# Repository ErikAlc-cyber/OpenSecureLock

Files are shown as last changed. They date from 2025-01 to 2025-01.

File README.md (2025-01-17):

# Open Secure Lock

### Descripción
Este proyecto presenta un **sistema de acceso inteligente** diseñado para mejorar la seguridad en unidades habitacionales y edificios departamentales. El prototipo combina tecnologías modernas, como **NFC**, **contraseñas numéricas**, y **detección de intrusiones**, para ofrecer una solución accesible, eficiente y confiable para proteger hogares frente a posibles robos o accesos no autorizados.

### Características Principales
- **Doble Autenticación:** Combinación de tarjetas NFC y contraseñas numéricas para maximizar la seguridad.
- **Detección de Intrusión:** Sensores infrarrojos y de presión que alertan sobre accesos no autorizados.
- **Notificaciones en Tiempo Real:** Alertas enviadas vía WhatsApp a usuarios y administradores en caso de intentos de acceso no autorizados.
- **Respaldo Energético:** Sistema alimentado por baterías recargables y puerto de carga externa para asegurar el funcionamiento incluso en cortes de energía.
- **Plataforma Web:** Gestión de usuarios y visualización de bitácoras de accesos mediante una interfaz web intuitiva.
- **Diseño Modular:** Facilita la instalación y el mantenimiento del sistema.

### Instalación
1. **Requisitos de Hardware:**
   - Microcontrolador Raspberry Pi Pico W.
   - Módulo NFC MFRC-522.
   - Pantalla LCD1602 I2C.
   - Sensores infrarrojos y de presión.
   - Otros componentes listados en la sección Inventario de Activos.

2. **Requisitos de Software:**
   - **Thonny IDE:** Para cargar y depurar el código en MicroPython.
   - **CallMeBot API:** Para enviar notificaciones vía WhatsApp.
   - **Biblioteca de LCD para pico:** para controlar la LCD. Encuéntrala [aquí!](https://github.com/T-622/RPI-PICO-I2C-LCD)

3. **Pasos para Configurar el Prototipo:**
   - [ ] Instalar y configurar los módulos de hardware según el Diagrama de Conexión.
   - [ ] Cargar el firmware en el microcontrolador utilizando el entorno de desarrollo.
   - [ ] Configurar las credenciales de usuario y administrador en la plataforma web.
   - [ ] Realizar pruebas iniciales para verificar el funcionamiento de los módulos.

### Cómo Funciona
1. **Acceso Seguro:**
   - El usuario escanea su tarjeta NFC y proporciona su contraseña numérica en el teclado.
   - Si la autenticación es exitosa, se desbloquea la cerradura electrónica.
2. **Alerta por Intrusión:**
   - Sensores detectan movimientos sospechosos o aperturas no autorizadas de la puerta.
   - Se envía una notificación a través de WhatsApp al usuario y administrador.
3. **Monitoreo y Gestión:**
   - La plataforma web permite realizar altas, bajas y cambios de usuarios, además de consultar bitácoras.

### Diseño de la Base de Datos

El sistema utiliza una base de datos estructurada que permite gestionar eficientemente la información de usuarios, accesos y registros de actividad. A continuación, se presenta el diseño de la base de datos:

#### Descripción
- **Usuarios:** Almacena información básica de los usuarios, como ID, nombre, tarjeta NFC asociada y contraseña encriptada.
- **Registros de Acceso:** Lleva un historial de accesos exitosos y fallidos, incluyendo la fecha y hora del intento.
- **Administradores:** Contiene las credenciales y permisos del administrador del sistema.
- **Configuraciones:** Guarda datos del sistema.

#### Diagrama de la Base de Datos
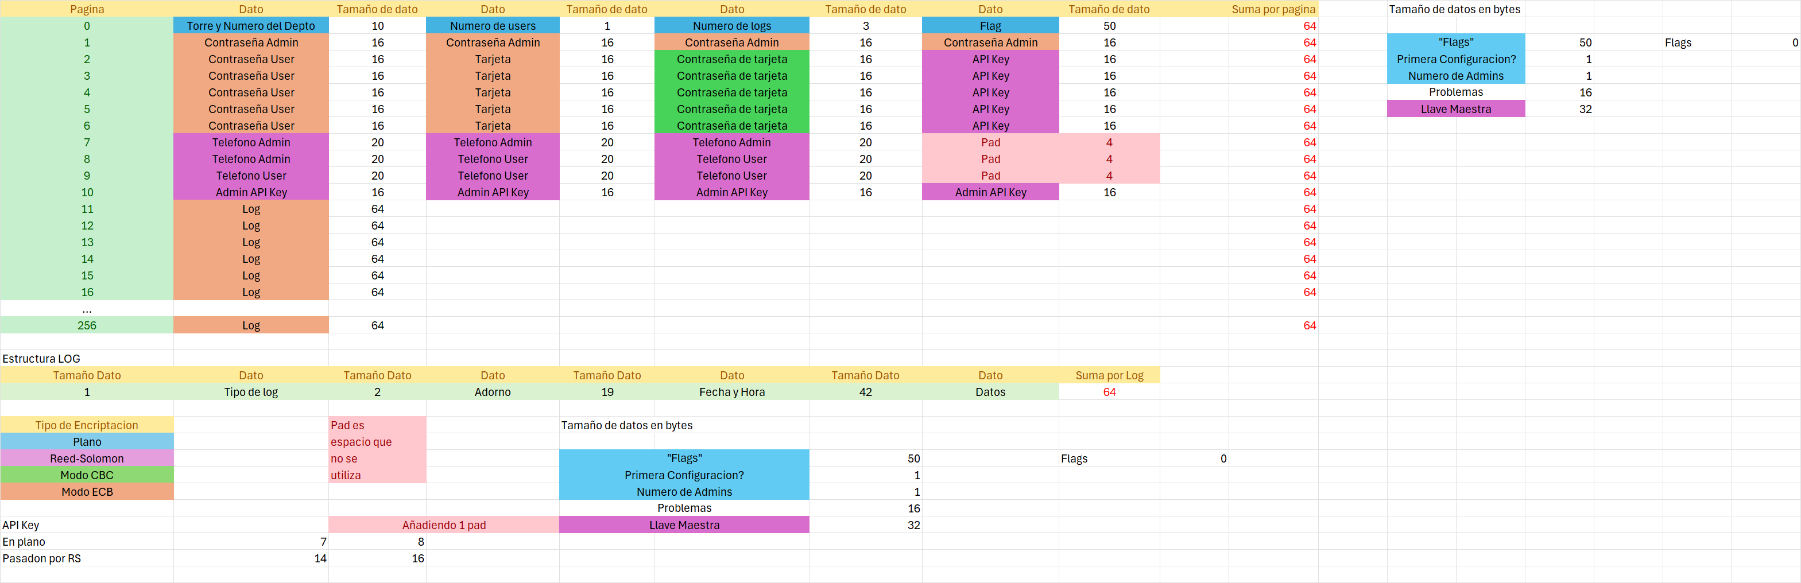
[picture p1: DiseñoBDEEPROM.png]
Diagrama de Base de Datos


#### Diagrama electrico
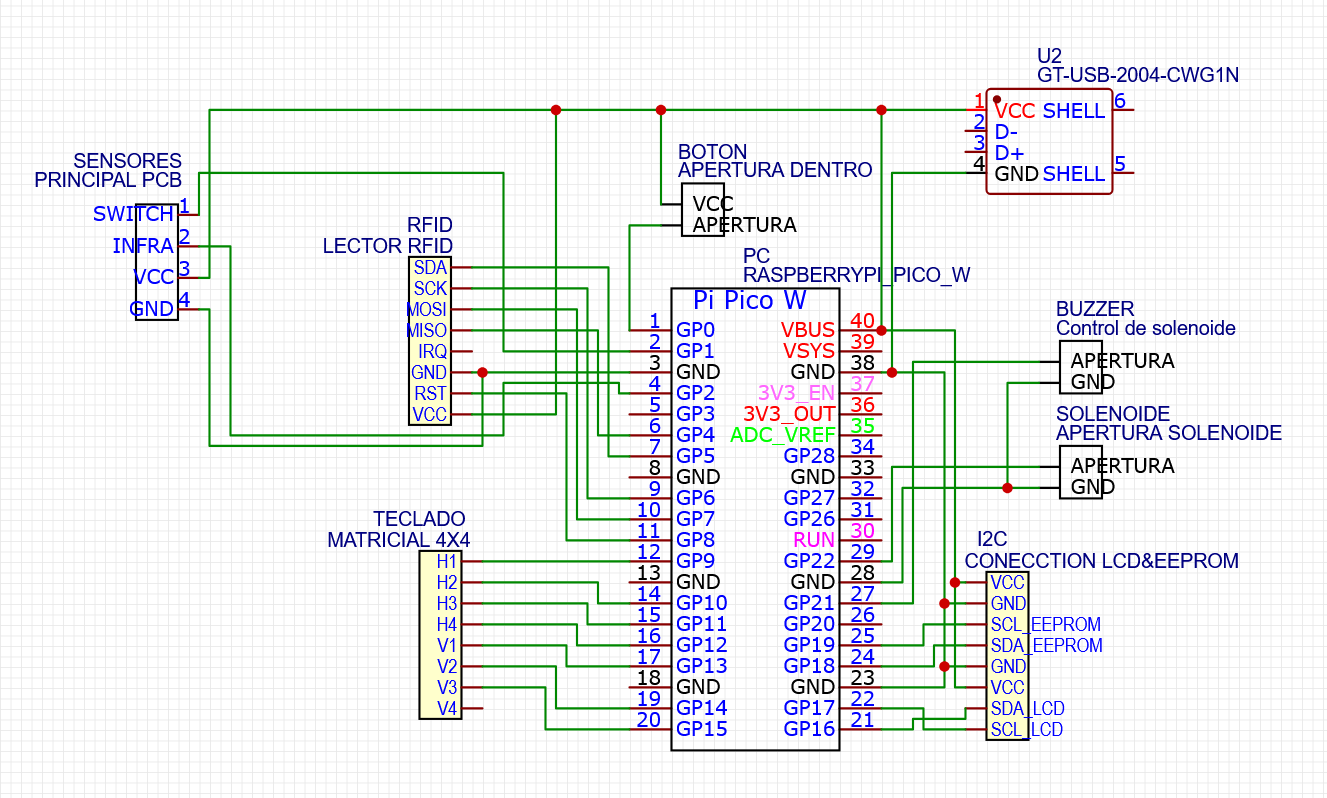
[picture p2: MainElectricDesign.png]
Diagrama de electrico principal

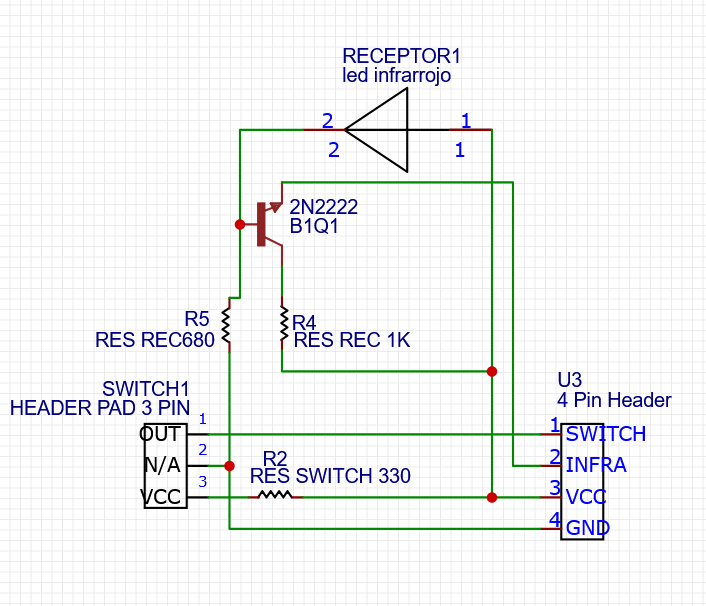
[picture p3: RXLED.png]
Diagrama de electrico de LED Receptor

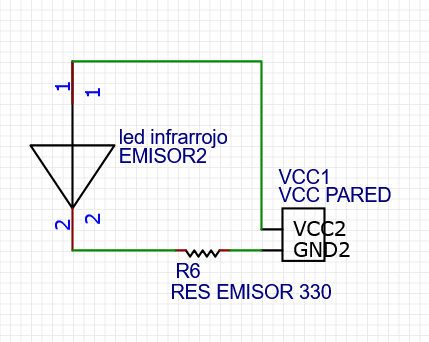
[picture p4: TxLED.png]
Diagrama de electrico de LED Transmisor


#### Prototipo Final
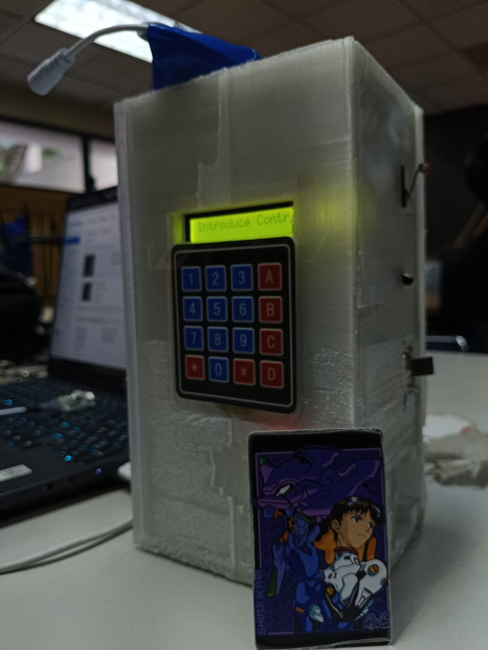
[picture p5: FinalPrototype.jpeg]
Prototipo Final


### Uso Futuro
El prototipo se puede expandir con:
- Integración de asistentes virtuales como Alexa o Google Assistant.
- Uso de teléfonos móviles con NFC como llaves de acceso.
- Adición de cámaras de vigilancia conectadas al sistema.

### Créditos
Desarrollado por:
- **Erik Alcántara Covarrubias** (ealcantarac1700@alumno.ipn.mx)
- **Benjamín Ortiz Rangel** (bortizr1600@alumno.ipn.mx)
- **Ana Paola Santos Mendoza** (asantosm1700@alumno.ipn.mx)

---

¡Contribuciones y retroalimentación son bienvenidas!

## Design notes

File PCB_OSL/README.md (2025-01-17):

# Diseño de la PCB para la cerradura

Este es el diseño completo de OSL, la PCB esta hecha para que se pueda mandar a pedir en una sola pieza y después romperla en los componentes necesarios

## Mejoras
Estamos concientes de que se puede mejorar la PCB, el diseño no es el final pero debe servir de base para después mejorarlo poco a poco

## Cómo usarlo

1. En el editor, abre el documento desde:  
   **Menú superior** → **Archivo** → **Abrir** → **EasyEDA**...  
2. Selecciona el archivo JSON correspondiente y ábrelo en el editor.  
3. Puedes guardar el diseño como un proyecto.

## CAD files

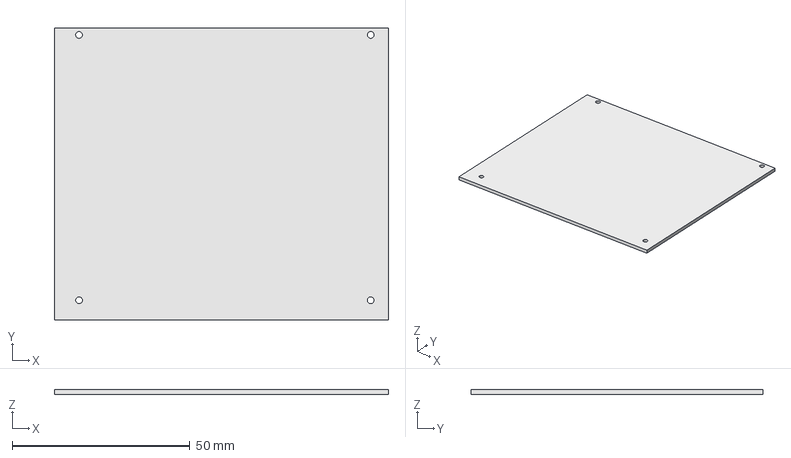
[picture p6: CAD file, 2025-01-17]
Case-3D-File/case.FCStd
93.9 x 82.0 x 1.40 mm

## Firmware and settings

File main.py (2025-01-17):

import mfrc522
from CAT24C256 import EEPROMManager
import keypad4x4
from ucryptolib import aes
import random
import time
import utime
from machine import Pin, PWM, I2C
from DatabaseManager import DatabaseManager as db
import rtc_config
from lcd_api import LcdApi
from pico_i2c_lcd import I2cLcd
from webserver import WiFiManager, WebServer
import uasyncio as asyncio
import sys
import network
import requests

MODE_CBC = 2
BLOCK_SIZE = 16
LCD_NUM_ROWS = 2
LCD_NUM_COLS = 16
LCD_ADDR = 0x27

# Configuracion de Hardware
BUZZER = PWM(Pin(21, mode=Pin.OUT))
BUZZER.freq(500)
OPEN_BTN = Pin(0, mode=Pin.IN, pull=Pin.PULL_DOWN)
DOOR_SENSOR = Pin(1, mode=Pin.IN, pull=Pin.PULL_DOWN)
IR_SENSOR = Pin(2, mode=Pin.IN, pull=Pin.PULL_DOWN)
DOOR_OUT = Pin(22, mode=Pin.OUT)

# Configuracion de la EEPROM
eeprom= EEPROMManager(0x50, 256, 1, 19, 18)
database = db()
database.read_general_info()

#Configuración LCD
i2c = I2C(0, sda=Pin(16), scl=Pin(17), freq=400000)
lcd = I2cLcd(i2c, LCD_ADDR, LCD_NUM_ROWS, LCD_NUM_COLS)
   
# Clase para inicializar la configuración
class setup_wizard:
    def __init__(self,newcode = False) -> None:
        self.newcode = newcode
        self.routes = [
            {
                '/': '/TT_pagina/Setupprincipal.html',
                '/edif': '/TT_pagina/Edificio.html',
                '/admin':'/TT_pagina/adminsetup.html',
                '/alta':'/TT_pagina/altasetup.html',
                '/config': '/TT_pagina/conectarsetup.html',
                '/styles':'/TT_pagina/styles.css',
            },
            {
                '/': '/TT_pagina/index.html',
                '/config': '/TT_pagina/conectarWifi.html',
                '/alta':'/TT_pagina/altaUsuario.html',
                '/baja':'/TT_pagina/bajaUsuario.html',
                '/cambio':'/TT_pagina/cambioUsuario.html',
                '/log':'/TT_pagina/logs.html',
                '/admin':'/TT_pagina/admin.html',
                '/styles':'/TT_pagina/styles.css',
            }]
        self.wifi_manager = WiFiManager(ssid="TT_2024-B037", password="12345678")
        prim_config = 1 if database.flags[0] == 49 else 0
        self.web_server = WebServer(self.wifi_manager, self.routes, prim_config)
    
    def no_config(self) -> None:
        """Genera una nueva contraseña aleatoria."""
        random_pwsd = [random.randint(0, 255) for _ in range(6)]
        self.newcode = True
        self.wifi_manager.start_ap()
        
    async def start(self):
        print("Iniciando servidor web en modo administración...")
        await self.web_server.start_server()

async def admin_mode(wizard):
    """Modo administración que inicia el servidor web."""
    wizard.no_config()
    await wizard.start()

# Clase para manejar tarjetas RFID
class RFIDCard:
    def __init__(self) -> None:
        self.uid = 0 # Identificador único de la tarjeta
        self.flag = False  # Indica si la tarjeta es válida
    
    def ReadData(self, block=8):
        """
        Lee los datos de la tarjeta RFID.
        
        :param block: Bloque de datos a leer (default: 8).
        :return: True si se leyó con éxito, False en caso contrario.
        """
        rdr = mfrc522.MFRC522(sck=6, miso=4, mosi=7, cs=5, rst=8)
        (stat, tag_type) = rdr.request(rdr.REQIDL)
        if stat == rdr.OK:
            (stat, raw_uid) = rdr.anticoll()
            if stat == rdr.OK:
                self.uid = "%02x%02x%02x%02x" % (raw_uid[0], raw_uid[1], raw_uid[2], raw_uid[3])
                if rdr.select_tag(raw_uid) == rdr.OK:
                    key = [0xFF, 0xFF, 0xFF, 0xFF, 0xFF, 0xFF]  # Clave de autenticación
                    if rdr.auth(rdr.AUTHENT1A, block, key, raw_uid) == rdr.OK:
                        data = rdr.read(block)
                        self.flag = True
                        return self.flag
                    else:
                        print("AUTH ERR")
                else:
                    print("Failed to select tag")
        
        database.save_log("Tarjeta: No se pudo leer la tarjeta",3)
        
            
    def WriteData(self, databytes, block=8):
        """
        Escribe datos en la tarjeta RFID.
        
        :param databytes: Datos a escribir.
        :param block: Bloque donde se escribirán los datos (default: 8).
        :return: True si se escribió con éxito, False en caso contrario.
        """
        rdr = mfrc522.MFRC522(sck=6, miso=4, mosi=7, cs=5, rst=8)
        (stat, tag_type) = rdr.request(rdr.REQIDL)
        if stat == rdr.OK:
            (stat, raw_uid) = rdr.anticoll()
            if stat == rdr.OK:
                if rdr.select_tag(raw_uid) == rdr.OK:
                    key = [0xFF, 0xFF, 0xFF, 0xFF, 0xFF, 0xFF] # Clave de autenticación
                    if rdr.auth(rdr.AUTHENT1A, block, key, raw_uid) == rdr.OK:
                        stat = rdr.write(block, databytes)
                        rdr.stop_crypto1()
                        if stat == rdr.OK:
                            self.flag = False
                            database.save_log("Tarjeta: Se creo nueva contraseña de acceso",2)
                            return self.flag
                        else:
                            database.save_log("Tarjeta: No se pudo escribir",3)
                            print("FAILED")
                    else:
                        print("AUTH ERR")
                        database.save_log("Tarjeta: Error de autenticacion",3)
                else:
                    print("Failed to select tag")
                    database.save_log("Tarjeta: No se pudo leer la tarjeta",3)
        else:
            print("stat Failure")
            database.save_log("Tarjeta: error en stat",3)
        
        return self.flag
    
    def ban_uid(self):
        """Reinicia el UID y la bandera de estado."""
        self.uid = ""
        self.flag = False 

# Clase para manejar los sensores de la puerta
class Door_sensors:
    def __init__(self)->None:
        self.ir_flag = True
        self.door_flag = True
        
    def irq_ir(self, Pin):
        """
        Interrupción para el sensor infrarrojo.
        """
        if(self.ir_flag):
            print("IR Sensor Triggered")
            database.save_log("Sensor: Sensor infrarojo activado",2)
            #send_message(phone_number, api_key, "Se detecto un intento de entrada sospechoso en su domicilio")
        utime.sleep(0.3)
    
    def irq_door(self, Pin):
        """Interrupción para el sensor de la puerta."""
        print("Door Sensor Triggered")
        if(self.door_flag):
            print("Empezar a sonar buzzer")
            BUZZER.duty_u16(10000)
            database.save_log("Sensor: Sensor de puerta activado",2)
            #send_message(phone_number, api_key, "Se detecto un intento de entrada sospechoso en su domicilio")
        utime.sleep(0.3)
    
    def irq_open(self, Pin):
        """Interrupcion para abrir la puerta con el boton proporcionado"""
        print("Interrupcion de apertura de puerta")
        self.defuse_door()
        self.defuse_ir()
        print("Sensores desactivados")
        DOOR_OUT.toggle()
        print("Solenoide Activado")
        DOOR_OUT.toggle()
        print("Solenoide desactivado")
        
                
    def defuse_door(self):
        """Desactiva la alarma de la puerta."""
        self.door_flag = False 
    
    def defuse_ir(self):
        """Desactiva la alarma del sensor infrarrojo."""
        self.ir_flag = False
        
    def change_state(self):
        while DOOR_SENSOR.value() == 1:
            utime.sleep(0.05)
            self.defuse_ir()
            self.defuse_door()
            
        while DOOR_SENSOR.value() == 0:
            utime.sleep(0.05)
            
        self.activate_def()
        
    def activate_def(self):
        """Activa ambas alarmas."""
        self.door_flag = True
        self.ir_flag = True 

def url_encode(input_string):
    """
    Codifica una string en formato URL.
    :param input_string: La string a codificar.
    :return: La string codificada en formato URL.
    """
    # Mapa de caracteres permitidos en URL
    allowed_chars = (
        "ABCDEFGHIJKLMNOPQRSTUVWXYZ"
        "abcdefghijklmnopqrstuvwxyz"
        "0123456789"
        "-_.~"
    )
    
    encoded_string = ""
    for char in input_string:
        if char in allowed_chars:
            encoded_string += char
        else:
            encoded_string += f"%{ord(char):02X}"  # Convierte a hexadecimal
    
    return encoded_string

def send_message(phone_number, api_key, message, debug=0):
    """
    Envia un mensaje por WhatsApp.

    :param phone_number: Número al que se enviará el mensaje.
    :param api_key: Clave de la API para ese número.
    :param message: Mensaje que se enviará.
    :param debug: Saber si se requiere el modo depurado.
    :return: Valor booleano.
    """
    url = f'https://api.callmebot.com/whatsapp.php?phone=+521{phone_number}&text={message}&apikey={api_key}'
    try:
        response = requests.get(url)
        if response.status_code == 200:
            if debug == 1:
                print(f"Mensaje enviado a {phone_number}: {message}")
            database.save_log(f"Mensaje enviado", 2)
            return True
        else:
            if debug == 1:
                print(f"Fallo al enviar mensaje a {phone_number}: {response.text}")
            return False
    except Exception as e:
        error = f"Error enviando mensaje: {str(e)}"
        if debug == 1:
            print(error)
        database.save_log(error, 3)
        return False
        
def send_bulk_messages(message, admin_only=False, debug=0):
    """
    Envia mensajes a todos los números telefónicos recuperados.

    :param message: Mensaje que se enviará.
    :param admin_only: Indica si solo se debe enviar a números de administradores.
    :param debug: Saber si se requiere el modo depurado.
    """
    try:
        # Recuperar teléfonos y API keys
        print("*****Empezando mensajeria masiva*****")
        message = url_encode(message)
        phone_numbers = database.read_phones()
        #TODO Solucionar API
        admin=1 if admin_only else 0
        api_keys = database.get_api(admin)

        # Validar que haya datos suficientes
        if len(phone_numbers) != len(api_keys):
            raise ValueError("El número de teléfonos no coincide con el de claves API.")
        
        for phone, api in zip(phone_numbers, api_keys):
            if len(api) == 7:  # Verificar que la clave API tenga la longitud correcta
                send_message(phone, api, message, 1)
            else:
                error = f"Clave API inválida para {phone}: {api}"
                if debug:
                    print(error)
                database.save_log(error, 3)

    except Exception as e:
        error = f"Error al enviar mensajes masivos: {str(e)}"
        print(error)
        if debug:
            print(error)
        database.save_log(error, 3)
   
def lcd_str(text, row=0, col=0, delay=0.3):
    """
    Muestra texto en el LCD, desplazándolo si excede el límite de caracteres por fila.
    text: String que se desea mostrar.
    row: Fila donde se inicia la impresión del texto.
    col: Columna inicial para comenzar la impresión.
    delay: Tiempo de retraso entre cada desplazamiento si el texto es largo.
    """
    lcd.clear()  # Limpia la pantalla antes de mostrar el nuevo texto
    text += " "

    # Calcula el límite de caracteres por fila
    max_chars = LCD_NUM_COLS - col

    # Si el texto cabe en la pantalla, simplemente mostrarlo
    if len(text) <= max_chars + 1:
        lcd.move_to(col, row)
        lcd.putstr(text)
    else:
        # Si el texto excede el límite, mostrarlo en partes
        start = 0
        end = max_chars
        while True:
            # Calcula la ventana del texto para mostrar en pantalla
            end = start + max_chars
            lcd.move_to(col, row)
            if end <= len(text):
                lcd.putstr(text[start:end])
            else:
                # Si el final excede el largo del texto, envuelve al inicio
                lcd.putstr(text[start:] + text[:end - len(text)])

            time.sleep(1)  # Espera antes de desplazar

            # Avanza en el texto y envuelve si llega al final
            start = (start + 1) % len(text)

def random_shuffle(cadena, semilla=None):
    """
    Mezcla aleatoriamente los caracteres de una cadena.
    
    :param cadena: Cadena a mezclar.
    :param semilla: Semilla para la aleatoriedad.
    :return: Cadena mezclada.
    """
    if semilla is not None:
        urandom.seed(semilla)
    
    caracteres = list(cadena)
    longitud = len(caracteres)
    
    for i in range(longitud):
        indice_aleatorio = random.randint(0, longitud - 1)
        caracteres[i], caracteres[indice_aleatorio] = caracteres[indice_aleatorio], caracteres[i]
    
    cadena_mezclada = ''.join(caracteres)
    return cadena_mezclada

def bytes_random(length):
    """
    Genera bytes aleatorios.
    
    :param length: Longitud de los bytes aleatorios.
    :return: Bytes aleatorios.
    """
    random_bytes = bytes([random.randint(0, 255) for _ in range(length)])
    return random_bytes

def create_key(raw_uid):
    """
    Crea una clave AES a partir del UID de la tarjeta RFID.
    
    :param raw_uid: UID de la tarjeta.
    :return: Clave cifrada.
    """
    aes_key = bytes_random(16)
    iv = bytes_random(16)
    cipher = aes(aes_key, 2, iv)
    plaintext = random_shuffle(raw_uid)
    pad = 16 - len(plaintext) % 16
    plaintext = plaintext + " "*pad
    encrypted = iv + cipher.encrypt(plaintext)
    return encrypted

def pad_data(data: str, length: int) -> str:
    if len(data) >= length:
        return data
    padded_data = data + ' ' * (length - len(data))
    return padded_data

def main_loop(intentos):
    """Ciclo principal del programa."""
    utime.sleep(1)
    BUZZER.duty_u16(0) # Apaga el zumbador
    admin_flag = False
    stage_1 = True
    stage_2 = False
    while True:
        #inicio = time.ticks_ms()        
            
        # Manejo de intentos
        if intentos >= 3:
            database.save_log("Se detecto intento de entrada sospechoso",2)
            #TODO Agregar mensaje whats
            send_bulk_messages(f"{database.depto_info}: Se detecto intento de entrada sospechoso", 1)
            #send_message(phone_number, api_key, "Se detecto intento de entrada sospechoso en su domicilio")
            intentos = 0
            stage_1 = True
            stage_2 = False
                
        if stage_1:
                
            #Introducir codigo en le keypad
            print("")
            print("Introduce Contra")
            print("")
            lcd_str("Introduce Contra", 0,0)
    
            psk_code = ""
            intentos += 1
            # Ciclo para hacer display de la contraseña
            while True:
                key = keypad.Keypad4x4Read()
                if key is not None:
                    print(f"Tecla presionada: {key} type: {type(key)}")
                    
                    if key == "#":  # Fin de la entrada
                        break
                    elif key == "*":
                        psk_code = psk_code[:len(psk_code) - 1]
                    else:
                        psk_code += key  # Agrega la tecla a la cadena
                    
                    display = "*" * len(psk_code)
                    lcd_str(display, 0,0)
                utime.sleep(0.3)  # Espera un tiempo para evitar múltiples lecturas
            
            pwd = pad_data(psk_code, 16)
            print(f"Texto pad: {pwd} type: {type(pwd)}")
            
            #TODO Modificar a leer de la eeprom
            if database.is_admin(pwd):
                sensores.defuse_ir()
                sensores.defuse_door()
                intentos = 0
                admin_flag = True
                lcd_str("Admin",0,0)
                print("****Se salio de Admin****")
                prim_config = False if database.flags[0] == 49 else True
                if prim_config:
                    lcd_str("Modo admin", 0,0)
                    asyncio.run(admin_mode(wizard))
                    admin_flag = False
                    del pwd
                    break
                database.save_log("Se ingreso contraseña administrador",1)
                
            if database.is_user(pwd):
                intentos = 0
                database.save_log("Se ingreso contraseña",1)
                if admin_flag:
                    psk_code = ""
                    lcd_str("1 Web / 2 Abrir", 0,0)
                    
                    while True:
                        key = keypad.Keypad4x4Read()
                        if key is not None:
                            
                            if key == "1":  # Fin de la entrada
                                lcd_str("Modo admin", 0,0)
                                database.save_log("Se activo modo admin",1)
                                asyncio.run(admin_mode(wizard))
                                admin_flag = False
                                del pwd
                                break
                            
                            elif key == "2":
                                lcd_str("Autorizado", 0,0)
                                mensaje = "Acceso concedido con codigo"
                                database.save_log(mensaje,1)
                                #TODO Agregar mensaje whats
                                #send_bulk_messages("Acceso concedido", True, 1)
                                DOOR_OUT.toggle()
                                stage_1 = True
                                stage_2 = False
                                intentos = 0
                                #TODO Agregar funcion cambio de estado
                                #sensores.change_state()
                                time.sleep(2)
                                DOOR_OUT.toggle()
                                del pwd
                                break
                            else:
                                lcd_str("Incorrecto", 0,0)
                                utime.sleep(2)
                            
                    
                        utime.sleep(0.3)  # Espera un tiempo para evitar múltiples lecturas
                else:
                    stage_1 = False
                    stage_2 = True
            
            else:
                psk_code = None
            pass
                    
        if stage_2:
            print("")
            print("Acerca Tarjeta")
            print("")
            lcd_str("Acerca Tarjeta", 0,0)
            
            if CardObject.ReadData(12):
                #TODO Cambiar a leer de la eeprom
                print(f"Tarjeta actual: {pad_data(CardObject.uid, 16)} Tarjeta de usuario: {database.usr_card}")
                if (pad_data(CardObject.uid, 16) == database.usr_card):
                    print("Tarjeta Autorizada")
                    if CardObject.flag:
                        print(f"Tarjeta flag: {CardObject.flag}")
                        new_key=create_key(CardObject.uid)
                        print(f"Llave nueva: {new_key}")
                        if CardObject.WriteData(new_key, 12):
                            lcd_str("Error", 0,0)
                            mensaje = "Error en tarjeta"
                            database.save_log(mensaje,3)
                        else:
                            lcd_str("Autorizado", 0,0)
                            page = database.usr_start_page + database.usr_id_num
                            #TODO Agregar update a medias
                            eeprom.partial_data(page, 48, new_key[:16])
                            mensaje = "Acceso concedido a tarjeta"
                            database.save_log(mensaje,1)
                            #TODO Agregar mensaje whats
                            #send_bulk_messages("Acceso concedido")
                            DOOR_OUT.toggle()
                            stage_1 = True
                            stage_2 = False
                            intentos = 0
                            #TODO Agregar funcion cambio de estado
                            #sensores.change_state()
                            time.sleep(2)
                            DOOR_OUT.toggle()
                    else:
                        lcd_str("Bloqueado", 0,0)
                        print("Bloqueado")
                        database.save_log("Tarjeta: Mas de 3 intentos, bloquear",2)
                        intentos += 1
                else:
                    lcd_str("No autorizado", 0,0)
                    print("No autorizado")
                    database.save_log("Tarjeta: Tarjeta no autorizada",2)
                    intentos += 1
                    pass
                utime.sleep(1)        
            #print("Tiempo de ejecucion: ", time.ticks_diff(time.ticks_ms(), inicio), " ms")
            

if __name__=="__main__":
    CardObject = RFIDCard()
    sensores = Door_sensors()
    keypad = keypad4x4.Keypad4x4()
    wizard = setup_wizard()
    
    DOOR_SENSOR.irq(trigger=Pin.IRQ_RISING,handler=sensores.irq_door)
    IR_SENSOR.irq(trigger=Pin.IRQ_FALLING,handler=sensores.irq_ir)
    OPEN_BTN.irq(trigger=Pin.IRQ_RISING,handler=sensores.irq_open)

    try:
        intentos = 0
        main_loop(intentos)
 
    except Exception as e:
            print("'--- Caught Exception ---'")
            sys.print_exception(e)
            print("'--- End of Exception ---'")

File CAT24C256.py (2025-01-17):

from machine import I2C, Pin
import re
import cryptolib
import ujson
import time

class CAT24C256(object):

    def __init__(self, i2c, i2c_addr, pages=512, bpp=64):
        self.i2c = i2c
        self.i2c_addr = i2c_addr
        self.pages = pages
        self.bpp = bpp # bytes per page

    def capacity(self):
        """Capacidad de almacenamiento en bytes"""
        return self.pages * self.bpp

    def read(self, addr, nbytes):
        """Leer uno o mas bytes the la eeprom EEPROM empezando por una direccion especifica"""
        return self.i2c.readfrom_mem(self.i2c_addr, addr, nbytes, addrsize=16)

    def write(self, addr, buf):
        """Escribir uno o mas bytes the la eeprom EEPROM empezando por una direccion especifica"""
        offset = addr % self.bpp
        partial = 0
        
        # partial page write
        if offset > 0:
            partial = self.bpp - offset
            self.i2c.writeto_mem(self.i2c_addr, addr, buf[0:partial], addrsize=16)
            time.sleep_ms(5)
            addr += partial
        
        # full page write
        for i in range(partial, len(buf), self.bpp):
            self.i2c.writeto_mem(self.i2c_addr, addr+i-partial, buf[i:i+self.bpp], addrsize=16)
            time.sleep_ms(5)
    
    def wipe(self):
        """Borra toda la eeprom"""
        buf = b'0' * self.bpp
        for i in range(self.pages):
            self.write(i*self.bpp, buf)


class EEPROMManager:
    """
    Clase para manejar la EEPROM con funciones de cifrado y descifrado.
    """

    def __init__(self, addr, size, i2c_number, pin_scl, pin_sda):
        """
        Inicializa el objeto EEPROMManager.
        """
        self.I2C_ADDR = addr
        self.EEPROM_SIZE = size
        self.i2c = I2C(i2c_number, scl=Pin(pin_scl), sda=Pin(pin_sda), freq=800000)
        self.control = CAT24C256(self.i2c,self.I2C_ADDR)
    
    def wipe_all(self):
        self.control.wipe()

    def pad_block(self, block, block_size=16, pad_byte=b' '):
        """
        Rellena un bloque de datos hasta block_size bytes con el byte dado.
        Por defecto, el byte de relleno es el espacio en blanco (0x20).
        """
        if not isinstance(block, bytes):
            raise TypeError(f"Se esperaba un objeto de tipo 'bytes', pero se recibió {type(block)}")
        
        padding_needed = block_size - len(block)
        if padding_needed > 0:
            block += pad_byte * padding_needed
        return block
    
    def partial_data(self, page, offset, data, debug = 0):
        """
        Actualiza parte de la pagina en la EEPROM sin reescribir la pagina.
        Parameters:
        - page: Numero de pagina a actualizar.
        - offset: El byte de inicio donde comenzar a sobreescribir.
        - data: Los nuevos datos a escribir (No exceder 64 bytes - offset bytes).
        - key: Llave de encriptacion.
    
        Returns:
        - None
        """
         # Verificar el tipo de data antes de procesar
        if debug == 1:
            print(f"Tipo de data: {type(data)}")
            print(f"Localizacion: pag-{page} pad-{offset}")
            print(f"Contenido de data: {data}")
        
        if isinstance(data, (bytearray)):
            data = bytes(data)

        data_length = len(data)
        if debug == 1:
            print(f"Longitud de data: {data_length}")

        if offset + data_length > 64:
            print(f"len bytes: {offset + data_length}")
            raise ValueError("Datos exceden el limite de bytes")

        current_data = self.read(page, 1)
        if debug == 1:
            print(f"PD: Data-{data}")
            print(f"current data: {current_data}")
        
        updated_data = bytearray(current_data) 
        if debug == 1:
            print(f"byte data: {updated_data}")
    
        updated_data[offset:offset + data_length] = data
        updated_data = bytes(updated_data)
        if debug == 1:
            print(f"Updated data: {updated_data}")
        
        print("Entrando a funcion self.save")
        self.save(updated_data, page)

    def secure_save(self, keys, data, page, debug=0):
        """
        Guarda datos de manera segura en la EEPROM utilizando cifrado AES.
        Permite el uso de diferentes llaves para diferentes segmentos de datos.
        
        keys: Lista de diccionarios que contienen:
            - 'key': la llave de encriptación
            - 'start': índice de inicio de datos para esta llave
            - 'end': índice de fin de datos para esta llave
        """
        data = bytes(data, 'utf-8')
        
        
        if debug == 1:
            print(f"Datos a guardar: {data}")
            
        encrypted_buffer = b''
        
        for segment in keys:
            key = segment['key']
            start = segment['start']
            end = segment['end']
        
            if isinstance(key, str):  # Si la clave es una cadena, conviértela a bytes
                key = key.encode('utf-8')
        
            aes = cryptolib.aes(key, 1)
            segment_data = data[start:end]
            encrypted_data = bytearray()
            
            for i in range(0, len(segment_data), 16):
                block = segment_data[i:i + 16]
                if len(block) < 16:
                    block += b'\x00' * (16 - len(block))
                encrypted_data.extend(aes.encrypt(block))
            segment_offset = start % self.control.bpp
            
        if debug == 1:
             print(f"Guardando en la pagina {page}, desde el offset {segment_offset} datos encriptados: {encrypted_data}")
        
        self.partial_data(page, segment_offset, encrypted_data, debug)

    def secure_read(self, keys, page, debug=0):
        """
        Lee datos de manera segura desde la EEPROM utilizando descifrado AES.
        Permite el uso de diferentes llaves para diferentes segmentos de datos.
    
        keys: Lista de diccionarios que contienen:
            - 'key': la llave de desencriptación
            - 'start': índice de inicio en la página para este segmento
            - 'end': índice de fin en la página para este segmento
        """
        page_address = page * 64
        decrypted_data = b''
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

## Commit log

2025-01-17 Primera Subida
    Hay varios errores conocidos, se arreglaran con el futuro
    [case.FCStd]
2025-01-17 Upload PCB Design
    PCB Final del prototipo, se puede mejorar
